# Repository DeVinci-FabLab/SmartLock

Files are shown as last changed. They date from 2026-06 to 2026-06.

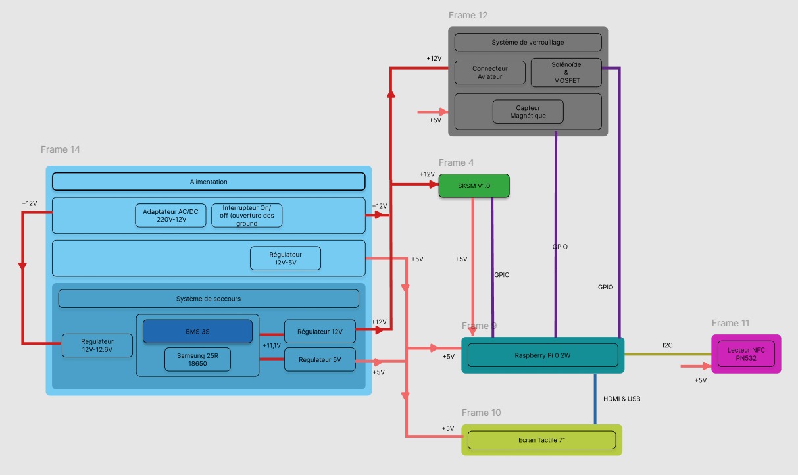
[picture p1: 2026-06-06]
deliverables/2_detailed_design/smartlock_elec_jalon2/smartlock_archi_elec_simplifiée.jpg

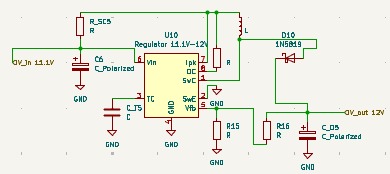
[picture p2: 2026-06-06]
deliverables/2_detailed_design/smartlock_elec_jalon2/smartlock_images_kicad/kicad7.jpg

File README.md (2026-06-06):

# SmartLock

Hub repository for the **DeVinci Fablab SmartLock** system, a badge-controlled connected-locker (*armoire connectée*) platform for managing self-service hardware and inventory.

> [!NOTE]
> This repository holds **no application code**. It is an **index**: each component lives in its own repository and is vendored here as a git **submodule** under [`submodules/`](./submodules), tracked on its `main` branch. Start here for how the pieces fit together, then open the submodule you need.

## Contents

- [Overview](#overview)
- [System architecture](#system-architecture)
- [Components](#components)
- [Design documentation](#design-documentation)
- [Repository layout](#repository-layout)
- [Getting started](#getting-started)
- [Build & deployment](#build--deployment)
- [License](#license)

## Overview

SmartLock controls access to fablab lockers with student NFC badges. Each locker holds an inventory of items (filament, electronic components, supplies). The system handles identification, per-locker permissions, inventory and stock, an append-only audit log, and an admin interface to manage all of it.

It splits into five repositories: the locker **hardware**, a central **backend** that acts as the single source of truth, and an **admin dashboard**.

## System architecture

```mermaid
graph TD
    User(["User · student badge"])

    subgraph locker["Connected locker — hardware"]
        IHM["SmartLock-IHM<br/>Touch interface · Python"]
        PCB["SmartLock-PCB<br/>Custom electronics board"]
        IHM --- PCB
    end

    Reader["SmartLock-Reader<br/>Auxiliary NFC reader<br/>ESP8266 + PN532"]
    Dashboard["SmartLock-Dashboard<br/>Admin web · SvelteKit"]

    subgraph backend["Backend — server"]
        Auth["SmartLock-Authentication-Authorization<br/>FastAPI · single source of truth"]
        KC[(Keycloak<br/>SSO / identities)]
        PG[(PostgreSQL<br/>data + audit log)]
    end

    User -->|NFC badge| IHM
    User -.->|read UID| Reader
    IHM -->|REST: identify, cart, unlock| Auth
    Dashboard -->|REST + JWT| Auth
    Auth --> KC
    Auth --> PG
```

At runtime the Authentication-Authorization API sits in the middle. The dashboard and the locker interface reach Keycloak and PostgreSQL only through it, never on their own. This diagram shows the intended wiring; see each repo for how far its integration has progressed.

## Components

| Component | Local path | Role | Stack |
|---|---|---|---|
| [**SmartLock-Authentication-Authorization**](https://github.com/DeVinci-FabLab/SmartLock-Authentication-Authorization) | [`submodules/SmartLock-Authentication-Authorization`](./submodules/SmartLock-Authentication-Authorization) | Core backend and single source of truth for identities, roles, permissions and audit. Validates NFC badge scans and exposes the REST API the dashboard and the locker interface call. | FastAPI · Keycloak · PostgreSQL |
| [**SmartLock-Dashboard**](https://github.com/DeVinci-FabLab/SmartLock-Dashboard) | [`submodules/SmartLock-Dashboard`](./submodules/SmartLock-Dashboard) | Internal admin web app for inventory, roles, stock, CSV purchase orders and audit history. A REST client of the auth API, with Keycloak SSO. | SvelteKit · shadcn-svelte |
| [**SmartLock-IHM**](https://github.com/DeVinci-FabLab/SmartLock-IHM) | [`submodules/SmartLock-IHM`](./submodules/SmartLock-IHM) | Touch interface on the locker: badge identification, cart, and unlock, talking to a backend REST API. | Python · CustomTkinter |
| [**SmartLock-Reader**](https://github.com/DeVinci-FabLab/SmartLock-Reader) | [`submodules/SmartLock-Reader`](./submodules/SmartLock-Reader) | Standalone auxiliary NFC reader. Shows scanned badge UIDs on a small web page over its own WiFi access point, with a copy button, useful when you need a card's UID. | ESP8266 + PN532 · Arduino |
| [**SmartLock-PCB**](https://github.com/DeVinci-FabLab/SmartLock-PCB) | [`submodules/SmartLock-PCB`](./submodules/SmartLock-PCB) | Custom electronics board for the locker hardware. | *Placeholder repo for now* |

## Design documentation

The `deliverables/` directory contains the full design record produced during the project, organized by phase.

| Folder | Contents |
|---|---|
| [`deliverables/1_state_of_art/`](./deliverables/1_state_of_art) | Concept convergence, state-of-the-art analysis, archival process |
| [`deliverables/2_detailed_design/`](./deliverables/2_detailed_design) | KiCAD schematics (PCB, power, NFC, Pi Zero 2W, lock driver…), component BOM, SolidWorks mechanical models, risk analysis |
| [`deliverables/4_subsystem_tests/`](./deliverables/4_subsystem_tests) | Subsystem test plan and results |
| [`deliverables/5_system_verification/`](./deliverables/5_system_verification) | System test report, user guide, maintenance guide, project retrospective (REX) |

The `CAD/` directory holds two standalone SolidWorks parts (`Boitier_Ext.SLDPRT`, `Cover_Ecran.SLDPRT`) for the external enclosure and screen cover.

## Repository layout

```plain
SmartLock/
├── CAD/                  Standalone SolidWorks parts (enclosure, screen cover)
├── deliverables/         Design and verification documents, organized by phase
│   ├── 1_state_of_art/
│   ├── 2_detailed_design/
│   ├── 4_subsystem_tests/
│   └── 5_system_verification/
├── docs/
│   └── DEPLOYMENT.md     Meta build & deployment guide (start here to deploy)
├── submodules/           Each component, tracked on its main branch
│   ├── SmartLock-Authentication-Authorization/
│   ├── SmartLock-Dashboard/
│   ├── SmartLock-IHM/
│   ├── SmartLock-Reader/
│   └── SmartLock-PCB/
├── .gitmodules
├── LICENSE
└── README.md
```

## Getting started

Clone the hub **with all submodules**:

```bash
git clone --recurse-submodules git@github.com:DeVinci-FabLab/SmartLock.git
```

If you cloned without `--recurse-submodules`, initialize them:

```bash
git submodule update --init --recursive
```

Pull the latest `main` of every component:

```bash
git submodule update --remote
```

Then follow each component's own `README.md` inside its directory to build and run it.

## Build & deployment

The end-to-end order, what to fabricate and deploy first and how the pieces come online, lives in **[`docs/DEPLOYMENT.md`](./docs/DEPLOYMENT.md)**. That file is the top-level guide; each component keeps its own detailed deployment docs in its repository.

## License

This project is licensed under the **MIT License**, Copyright (c) 2025 DeVinci Fablab. See [`LICENSE`](./LICENSE) for details. Each submodule carries its own license (MIT as well at the time of writing).

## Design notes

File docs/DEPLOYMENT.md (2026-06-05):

# Build & Deployment Guide

This is the top-level guide for the whole SmartLock system. It gives the **order** in which to fabricate the hardware and deploy the services, and how each piece comes online. Each component keeps its own detailed deployment docs in its repository; this guide tells you what to do first and how it fits together, then points you there.

## Contents

- [Prerequisites](#prerequisites)
- [Build & deployment order](#build--deployment-order)
  - [Phase 1 — Locker hardware](#phase-1--locker-hardware)
  - [Phase 2 — Identity & backend](#phase-2--identity--backend)
  - [Phase 3 — Admin dashboard](#phase-3--admin-dashboard)
  - [Phase 4 — Commission the locker](#phase-4--commission-the-locker)
- [Shared deployment conventions](#shared-deployment-conventions)

## Prerequisites

- A Linux server reachable from the fablab network. The stack is self-hosted, with no cloud serverless.
- **Docker** + **Docker Compose v2** on the server.
- **Traefik** running as the reverse proxy, with an external Docker network (referenced below as `traefik-network`).
- DNS records pointing your domains (`auth.…`, `api.smartlock.…`, `dashboard.smartlock.…`) to the server's public IP.
- `VOLUMES_PATH` defined in the server environment (see [conventions](#docker-volumes)).

> [!NOTE]
> The containerized services (API, Dashboard) follow the shared conventions in the [last section](#shared-deployment-conventions). Read it once; it applies to every service.

## Build & deployment order

Build from the physical layer up: the locker first, then the backend it talks to, then the admin tooling on top.

```mermaid
graph LR
    A["1 · Locker hardware<br/>PCB · IHM · enclosure"] --> B["2 · Identity & backend<br/>Keycloak → API + PostgreSQL"]
    B --> C["3 · Admin dashboard<br/>SvelteKit"]
    C --> D["4 · Commission<br/>wire IHM → API, enroll badges"]
```

### Phase 1 — Locker hardware

Fabricate and assemble the physical locker before anything else. The rest of the system has nothing to talk to until a locker exists.

1. **PCB**: fabricate or order the custom electronics board, see [`SmartLock-PCB`](../submodules/SmartLock-PCB).
2. **Enclosure and mechanics**: the locker model, lock actuator and wiring.
3. **IHM**: install the touch interface on the locker and flash it, see [`SmartLock-IHM`](../submodules/SmartLock-IHM). You wire it to the API in Phase 4.
4. **Reader** (optional, auxiliary): flash the standalone NFC reader, see [`SmartLock-Reader`](../submodules/SmartLock-Reader). Use it to read a badge UID when you need one.

At the end of this phase you have a powered locker with a touch screen, not yet connected to any backend.

### Phase 2 — Identity & backend

Deploy the single source of truth next. Order matters inside this phase: **Keycloak first**, then the API and database.

1. **Keycloak**: deploy it, then configure the realm, clients, roles and groups.
2. **API + PostgreSQL**: deploy [`SmartLock-Authentication-Authorization`](../submodules/SmartLock-Authentication-Authorization). Migrations run automatically on container start, and the API needs Keycloak reachable.

That repo holds the detailed steps (SSH commands, env vars, realm setup):

- `docs/deployment.md` for the full server deployment guide
- `docs/keycloak-test-guide.md` for the realm, clients, roles and groups
- `docs/system-design.md` for the architecture, auth flows and data model

Check it: the API answers at `https://api.smartlock.devinci-fablab.fr`, with Swagger UI at `/docs`.

### Phase 3 — Admin dashboard

With the API live, deploy the admin web app, see [`SmartLock-Dashboard`](../submodules/SmartLock-Dashboard).

1. Register a Keycloak client for the dashboard (OIDC + PKCE).
2. Fill `web/.env` (API URL, Keycloak issuer and client, session secret), see the dashboard README.
3. Deploy the hardened production image (`just prod`, `adapter-node`, healthcheck on `/health`).

The dashboard is a REST client of the API; it never talks to Keycloak or PostgreSQL directly.

### Phase 4 — Commission the locker

Tie it all together:

1. Point the **IHM** on the locker at the production API URL.
2. Enroll badges: read UIDs with the Reader (or the IHM) and grant locker permissions in the Dashboard.
3. Run a full pass: badge scan → identification → cart → unlock, then confirm the action lands in the audit log.

---

## Shared deployment conventions

The DeVinci Fablab conventions below apply to every containerized service (API, Dashboard). The per-repo deployment docs refer back to them.

### Docker volumes

Volumes live under a single directory to ease management and backup. The server environment defines the root as `VOLUMES_PATH`.

```yaml
services:
  your-service:
    image: ...
    volumes:
      - ${VOLUMES_PATH}/your_service_name/volume1:/my/volume1
      - ${VOLUMES_PATH}/your_service_name/volume2:/my/volume2
```

> [!NOTE]
> A variable like `VOLUMES_PATH`, not managed by the end user, lets you move the volume root without editing every service's configuration.

### Multi-stage Docker images

Service images use multi-stage builds: a shared `base` stage, then split `dev` and production (`serve`) stages, so one `Dockerfile` builds both and you pick the target. Production stages should:

- `EXPOSE` and bind the app to an explicit `--port` (used by the healthcheck and Traefik).
- copy the source into the image so the container runs standalone, with no bind-mounted volume.
- declare a `HEALTHCHECK` that runs a small `healthcheck.sh`.

A typical healthcheck script tries `wget --spider` (or `curl --fail`) against `http://0.0.0.0:<port>/` and exits non-zero on failure.

### CD pipeline → GHCR

Each service ships a CD workflow under `.github/workflows/`. On every push to `main` it builds the production image and pushes it to the GitHub Container Registry:

```yaml
on:
  push:
    branches: [main]

permissions:
  contents: read
  packages: write
```

Per service you only change the build step's `target` (the production stage) and `tags`, following the format `ghcr.io/devinci-fablab/<service_name>:<tag>`: `<service_name>` lowercase with no spaces, and `<tag>` being `latest` plus the commit SHA.

### Traefik integration

In production, do not publish `ports`; Traefik handles routing. Put the service on the external `traefik-network` and add labels (replace `documentation` with your unique service name, lowercase, no spaces):

```yaml
services:
  your-service:
    image: ghcr.io/devinci-fablab/<service_name>:latest
    restart: unless-stopped
    security_opt:
      - no-new-privileges:true
    deploy:
      mode: replicated
      replicas: 2
    labels:
      - 'traefik.enable=true'
      - 'traefik.http.routers.documentation.rule=Host(`docs.devinci-fablab.fr`)'
      - 'traefik.http.routers.documentation.entrypoints=websecure'
      - 'traefik.http.routers.documentation.tls.certresolver=myresolver'
      - 'traefik.http.services.documentation.loadbalancer.server.port=3000'
      - 'com.centurylinklabs.watchtower.enable=true'
    networks:
      - traefik-network

networks:
  traefik-network:
    external: true
```

- `rule=Host(...)`: the domain that routes to this service; it must point to the server's IP.
- `loadbalancer.server.port`: the port the app listens on inside the container (matches `EXPOSE` and `--port`).
- `deploy.replicas`: run N instances for redundancy and load balancing.

> [!NOTE]
> Publishing container ports can override firewall rules, which is usually not what you want. [Read more](https://www.baeldung.com/linux/docker-container-published-port-ignoring-ufw-rules).

### Watchtower

The `com.centurylinklabs.watchtower.enable=true` label lets **Watchtower** pull and redeploy a service when a new image reaches GHCR, closing the loop with the CD pipeline.

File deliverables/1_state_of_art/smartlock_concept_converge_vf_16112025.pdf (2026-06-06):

# SmartLock

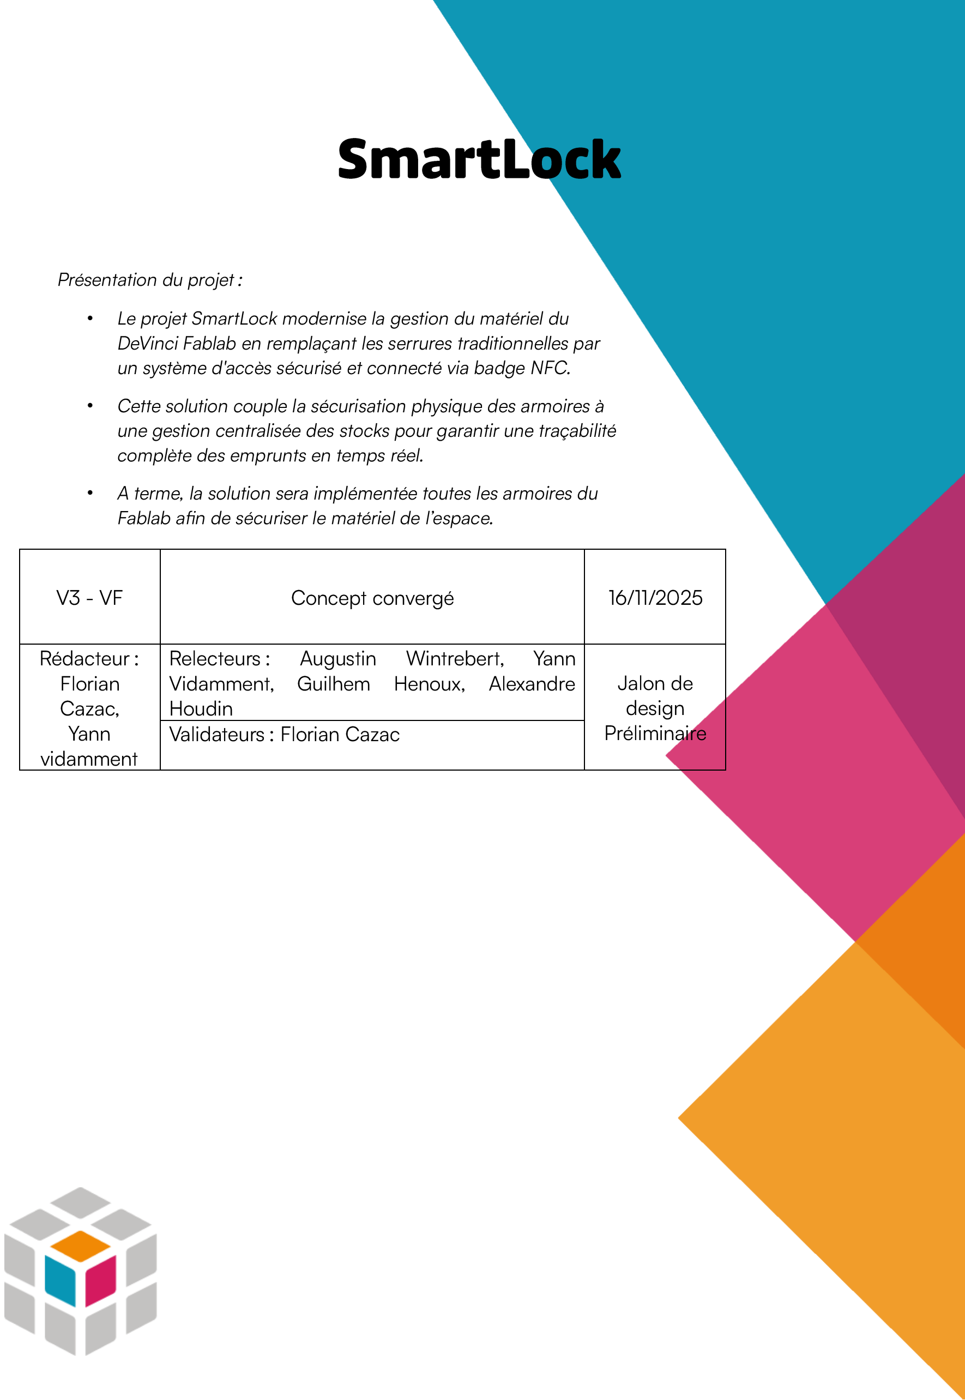
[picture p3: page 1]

V3 - VF | Concept convergé | 16/11/2025

Rédacteur :
Florian
Cazac ,
Yann
vidamment
Relecteur s : | Augustin Wintrebert, | Yann
Vidamment, | Guilhem Henoux, Alexandre
Houdin | | Jalon de design
Validateurs : Florian Cazac | Préliminaire

Présentation du projet :

- Le projet SmartLock modernise la gestion du matériel du DeVinci Fablab en remplaçant les serrures traditionnelles par un système d'accès sécurisé et connecté via badge NFC.
- Cette solution couple la sécurisation physique des armoires à une gestion centralisée des stocks pour garantir une traçabilité complète des emprunts en temps réel.
- A terme, la solution sera implémentée toutes les armoires du Fablab afin de sécuriser le matériel de l’espace.

## Table des matières

## 1. Introduction

Ce document s'inscrit dans le cadre du Jalon de Design Préliminaire. Il formalise le concept convergé de notre système d'armoire connectée, en détaillant l'architecture matérielle et logicielle retenue. S'appuyant sur le retour d'expérience du modèle DVIC, cette solution technique constitue le socle validé nécessaire pour engager la phase de développement détaillé et de réalisation.

## 2. Scénarios d'Utilisation et Protocoles d'Urgence

Cette section présente les séquences d’actions en conditions normales ainsi que les procédures prévues en cas d’incident. L’analyse de ces différents cas d’usage a permis d’identifier clairement les composants nécessaires au bon fonctionnement du système.

2.1. Utilisation Normale (Cas Nominal)
1. Authentification : L'utilisateur s'approche du casier et présente son badge NFC
2. Validation : Le système vérifie les droits d'accès du badge. Si valide, il déclenche
3. Opération : L'utilisateur ouvre la porte, effectue son dépôt ou retrait d'objets,
- Note : Une étape de déclaration d'objets via l'interface tactile est
4. Enregistrement : Le système détecte la fermeture physique de la porte, verrouille le mécanisme et enregistre la transaction (mise à jour de l'inventaire en
5. Confirmation : Un message de succès s'affiche sur l'écran tactile pour informer
6. Fin : L'utilisateur quitte la zone.

2.2. Gestion d'une Coupure de Courant
2.2.1. Courte Durée

Le système permet le maintien des portes par défaut.

1. Détection : Une perte d'alimentation secteur survient pendant une transaction.
2. Continuité : Le système bascule immédiatement sur la batterie interne (autonomie estimée : ~30 min), garantissant notamment l’ouverture des portes.
3. Alerte : Une notification (mail, message, etc.) avertit les membres du bureau de
4. Rétablissement : Lorsque le courant revient, l’alimentation secteur reprend automatiquement sans perturbation du service.
2.2.2. Prolongée
1. Mode Dégradé : La coupure persiste. Le système continue de fonctionner sur
2. Avertissement : L'interface envoie une notification critique concernant
3. Arrêt : Une notification finale s’envoie, puis le système s'éteint proprement via le
4. Continue : Si un utilisateur souhaite accéder à l’armoire alors que le courant n’est toujours pas rétabli, il peut la connecter à une batterie externe pour réalimenter le système et permettre l’ouverture des portes.
5. Reprise : Le système redémarre automatiquement et reprend son fonctionnement normal une fois l'alimentation secteur rétablie.
2.3. Procédure d'Accès d'Urgence (Hardware)
1. Accès physique : En cas de panne critique ou d'urgence absolue, le personnel autorisé intervient sur le boîtier externe (situé au niveau du connecteur aviateur).
2. Effraction contrôlée : Le boîtier est brisé pour accéder à la mécanique interne.
3. Ouverture manuelle : L'opérateur active le module de déverrouillage manuel
4. Maintenance : L'opérateur remet le système en état (réparation du boîtier et vérification électronique) avant la remise en service.

## 3. Mecatronique

3.1. Électronique et Contrôleur

Le cœur du système embarqué a fait l'objet d'une étude comparative approfondie pour équilibrer coût, performance et connectivité.

Unité de Calcul et Affichage Initialement, la | Raspberry | Pi 4 a été envisagée mais
écartée en raison de son coût prohibitif pour un déploiement à grande échelle. De
même, l'ESP32 S3 a été rejeté en raison des complexités liées au développement d'une
interface graphique avancée. Le choix définitif s'est donc arrêté sur la | Raspberry | Pi
Zero 2W . Ce modèle présente l'avantage décisif d'intégrer nativement la | connectivité
WiFi , simplifiant grandement l'architecture réseau tout en restant économiquement viable.

Cette unité pilotera un écran tactile de 7 pouces , servant d'interface directe pour l'utilisateur. Le stockage du système d'exploitation ainsi que les journaux d'événements
(faisant office de "boîte noire") seront assurés par une | carte SD . Enfin, la gestion de
l'arrêt du système sera sécurisée par un module | SKSM V1.0 , garantissant une
extinction propre du système d'exploitation et une gestion optimisée de l'alimentation.
3.2. Capteurs, Mécanismes et Sécurité

La sécurité physique et numérique de l'armoire repose sur des composants sélectionnés pour leur robustesse face aux tentatives d'intrusion.

Authentification RFID/NFC | : Contrairement aux cartes | Mifare Ultralight souvent
utilisées, le projet exige un niveau de sécurité supérieur. Le choix s'est porté sur la technologie NFC MIFARE DESFire EV3 . Cette décision est motivée par le chiffrement avancé des données sur la carte, prévenant efficacement les risques de clonage. En
conséquence, le module de lecture | PN532 a été sélectionné pour sa capacité à lire ce
protocole spécifique, ce que ne permettait pas le module standard | RC522 .

Système de Verrouillage : Le mécanisme de fermeture conserve le principe éprouvé
des armoires du DVIC, utilisant un | solénoïde (Solenoid lock) qui vient bloquer la came
batteuse , voir dessin . La logique de fonctionnement est de type " | Fail Secure " : le
système est verrouillé lorsqu'il n'est pas alimenté (le solénoïde est tendu par défaut) et
ne se déverrouille (rétractation) que lors de l'application d'un courant. Pour compléter
ce dispositif, un capteur magnétique (door sensor) détectera la fermeture effecti ve de la porte, signalant au système de couper l'alimentation du solénoïde pour réengager le verrouillage en toute sécurité. Des LEDs ou un buzzer sont envisag és afin d’inciter l’utilisateur à mettre à jour les stocks.

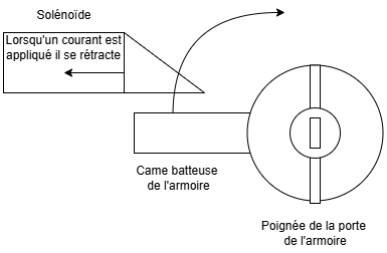
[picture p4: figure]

3.3. Gestion de l'Alimentation

L'alimentation du système est conçue pour être résiliente, avec une source principale
sur secteur transformée (max 12V pour le solénoïde) et un système de secours.

Une batterie de secours est intégrée pour maintenir les fonctionnalités critiques et éviter
le blocage de l'armoire en cas de panne secteur. Le modèle retenu est une | Samsung
25R 18650 (2500 mAh, 3.7V, 20A). Pour adapter la tension de cette batterie aux besoins du système, un convertisseur " boost " (step-up) sera nécessaire afin d'élever la
tension vers une plage de | 9 -12V . L'ensemble du circuit de puissance inclura des
composants de protection indispensables, notamment un | interrupteur | (switch), un
fusible de sécurité, ainsi qu'un connecteur aviateur pour une interface d'alimentation externe robuste .

Figure 1Dessin du système de verrouillage

## 4. Architecture Informatique

L'architecture logicielle du projet est conçue pour assurer une séparation claire entre le serveur central et le client embarqué sur l'armoire, garantissant ainsi modularité et

Infrastructure Serveur | : La partie backend du serveur repose sur | Fast API en
Python , une solution performante pour la gestion des requêtes. Pour l'interface d'administration (frontend), le choix s'est porté sur Svelte , un framework JavaScript. Ce choix marque une rupture avec celui de MyFab (qui utilise Next.js), car Svelte est jugé plus convivial ( user-friendly ) et plus simple à maintenir pour les équipes futures. La persistance des données, notamment la gestion des stocks, est assurée par une base
de données PostgreSQL , tandis que la gestion des utilisateurs et des accès s'orientera vers l'utilisation du protocole LDAP .

Interface Client (Embarqué) : Sur l'armoire elle -même, un client local développé en Python sera exécuté. Son rôle principal est de servir de passerelle, effectuant les appels API nécessaires vers le serveur. L'interface utilisateur (GUI) sera développée à l'aide de la librairie standard TkInter . Toutefois, pour s'affranchir de l'aspect austère par défaut de TkInter et garantir une interface moderne et épurée, le développement s'appuiera
spécifiquement sur la bibliothèque surcouche | CustomTkinter .
Workflow d'autorisation | :
1. L’utilisateur présente son badge NFC (13,56 MHz) au lecteur PN532.
2. Le lecteur récupère l’UID et le transmet au Raspberry Pi via le bus SPI.
3. L’application Python3 envoie la requête d’autorisation au serveur distant via WiFi.
a. Les informations sensibles (UID, identifiant du casier) | ne sont jamais
affichées en clair | sur l’interface.
b. La communication est sécurisée via | SSL/TLS pour chiffrer les échanges.
4. Le serveur, via son API REST, vérifie les permissions de l’utilisateur.
a. Idéalement, il interroge le LDAP pour confirmer que l’utilisateur a le droit d’accéder à cette armoire.
5. Le serveur renvoie un statut d’autorisation : accès accepté ou refusé.
6. Si l’accès est validé, le Raspberry Pi active le relais correspondant pour déverrouiller la serrure.
7. L’interface graphique TkInter affiche simplement le résultat : “Accès autorisé” ou “Accès refusé” , sans divulguer d’informations sensibles.

## 5. Liste de s composants mentionnés

5.1. Gestion de l'Alimentation

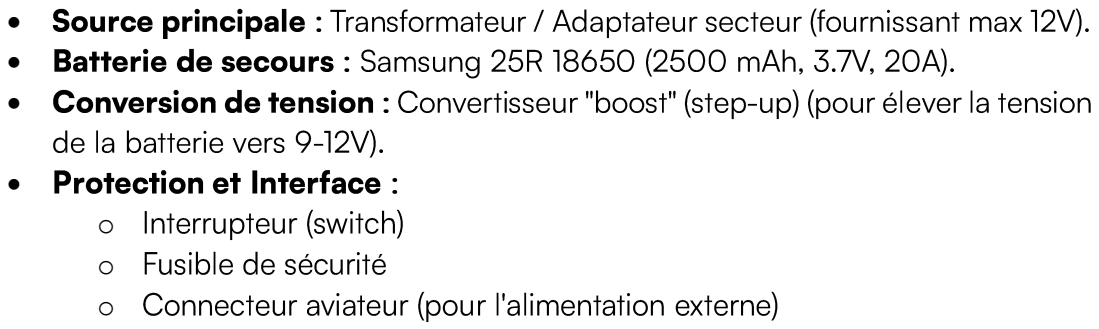
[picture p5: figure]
de la batterie vers 9 -12V). • Protection et Interface : • Interrupteur (switch) • Fusible de sécurité

- Source principale : Transformateur / Adaptateur secteur (fournissant max 12V).
- Batterie de secours : Samsung 25R 18650 (2500 mAh, 3.7V, 20A).
- Conversion de tension : Convertisseur "boost" (step -up) (pour élever la tension
- Connecteur aviateur (pour l'alimentation externe)
5.2. Électronique et Contrôleur
- Unité de calcul : Raspberry Pi Zero 2W (avec WiFi intégré).
- Interface utilisateur : Écran tactile de 7 pouces.
- Gestion alimentation OS : Module SKSM V1.0 (pour l'extinction propre).
5.3. Capteurs, Mécanismes et Sécurité

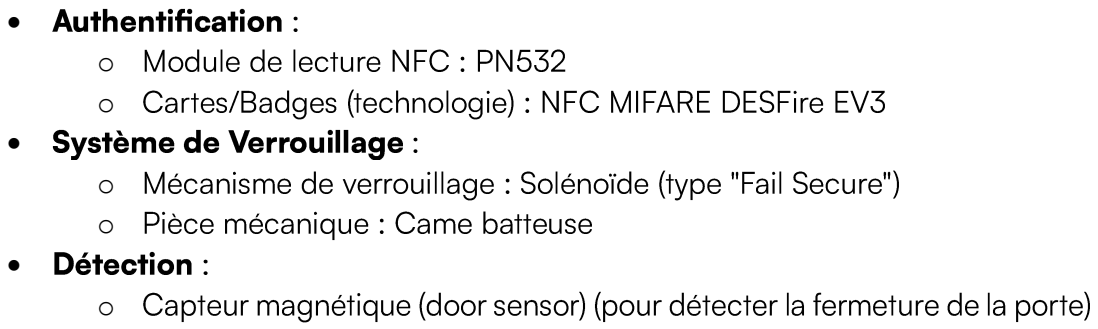
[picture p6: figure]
• Authentification; • Module de lecture NFC : PN532; • Système de Verrouillage :; • Pièce mécanique : Came batteuse • Détection :

- Cartes/Badges (technologie) : NFC MIFARE DESFire EV3
- Mécanisme de verrouillage : Solénoïde (type "Fail Secure")
- Capteur magnétique (door sensor) (pour détecter la fermeture de la porte)
5.4. Signalisation (Composants envisagés)
- LEDs
- Buzzer

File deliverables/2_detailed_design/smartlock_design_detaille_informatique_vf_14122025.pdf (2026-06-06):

# SmartLock

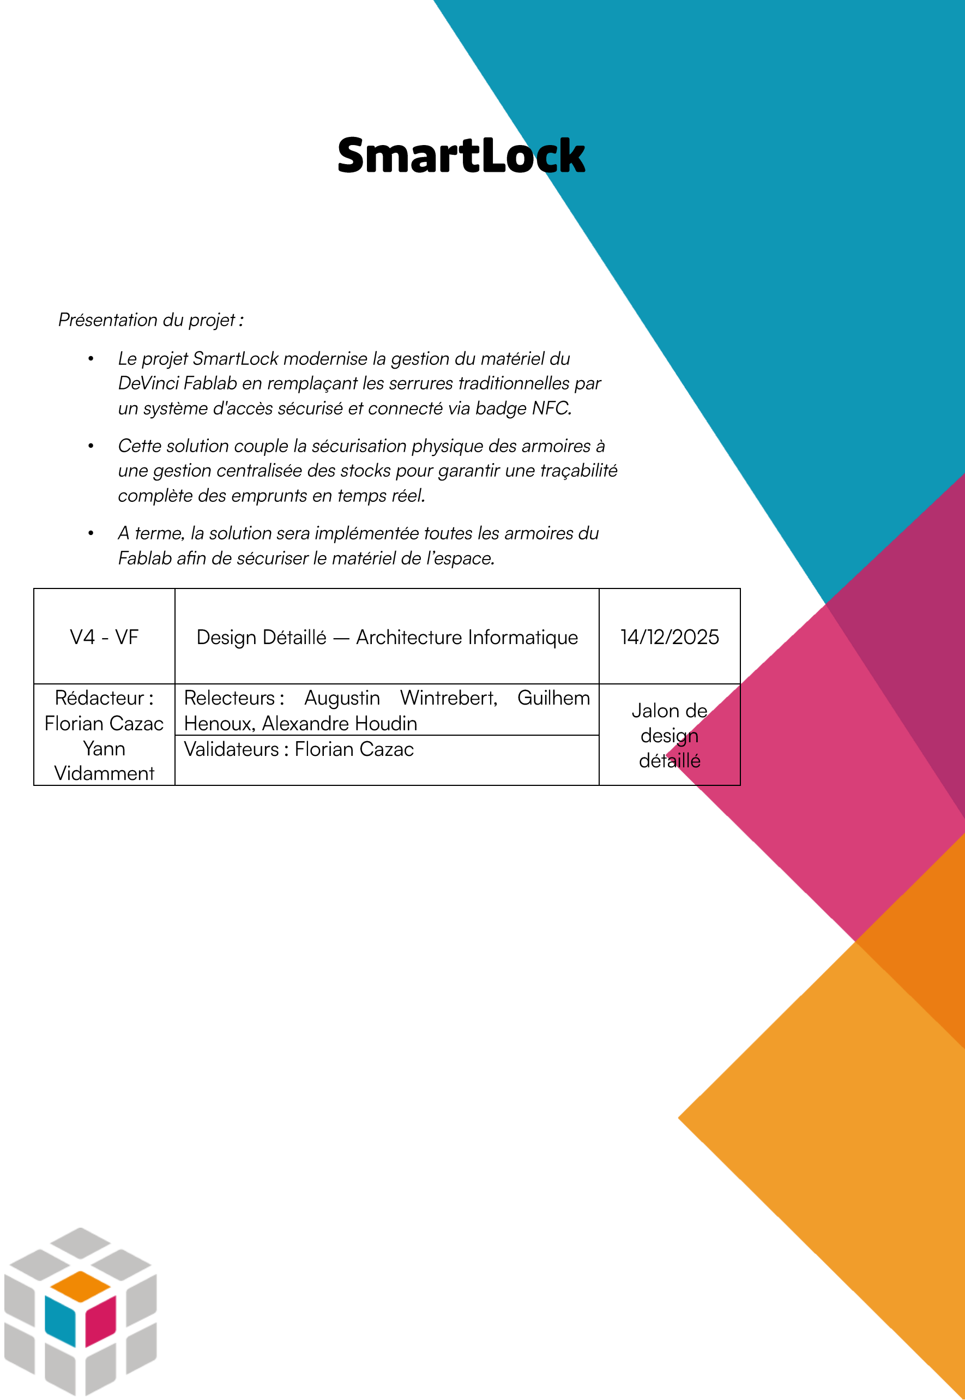
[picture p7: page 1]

V4 - VF | Design Détaillé – Architecture Informatique | 14/12/2025
Rédacteur : Florian Cazac Yann Vidamment | Relecteur s : Aug ustin Wintrebert , Gui lhem Henoux, Alexandre Houdin | Jalon de design

détaillé Validateurs : Florian Cazac

Présentation du projet :

- Le projet SmartLock modernise la gestion du matériel du DeVinci Fablab en remplaçant les serrures traditionnelles par un système d'accès sécurisé et connecté via badge NFC.
- Cette solution couple la sécurisation physique des armoires à une gestion centralisée des stocks pour garantir une traçabilité complète des emprunts en temps réel.
- A terme, la solution sera implémentée toutes les armoires du Fablab afin de sécuriser le matériel de l’espace.

## Table des matières

## 1. Introduction

Ce document définit l'architectur e informatique globale,serveur et logicielle détaillée du client embarqué pour le projet SmartLock.

## 2. Architecture globale

L'architecture logicielle du projet est conçue pour assurer une séparation claire entre le serveur central et le client embarqué sur l'armoire, garantissant ainsi modularité et

2.1. Infrastructure Serveur

Le serveur central est le cerveau du système, hébergé sur une machine distante.

2.1.1. Authentification

Architecture d'authentification

Le système d'authentification du casier intelligent repose sur un compte de service (authentification machine -à-machine) qui interroge l'API Admin de Keycloak

Séquence d'authentification

Lorsqu'une carte NFC est scannée, le processus suivant est exécuté :

1. Lecture : Capture de l'UID de la carte NFC
2. Requête : Envoi de l'UID à l'API backend du casier
3. Authentification : Le système s'authentifie auprès de Keycloak avec les identifiants du compte de service
4. Recherche | : Identification de l'utilisateur possédant l'attribut | nfc_card_id
correspondant
5. Récupération : Obtention des rôles et permissions associés à l'utilisateur
6. Autorisation : Décision d'accès au casier basée sur les rôles de l'utilisateur
7. Traçabilité : Enregistrement de la transaction avec le contexte utilisateur complet

Nous avons fait le choix pragmatique d'utiliser Keycloak dans sa version standard, en exploitant simplement son API Admin et ses comptes de service natifs. Cette approche
nous évite tout développement spécifique complexe : le système est ainsi plus robuste | ,
facile à maintenir, et les mises à jour se font sans risque de régression. | Il centralise la
gestion des identités, qu'il s'agisse de l'accès web (SSO) ou des badges NFC, assurant
une cohérence totale des droits.

2.1.2. Base de Données

PostgreSQL a été retenu comme système de gestion de base de données relationnelle pour assurer la persistance des données métier. Cette solution stocke de manière structurée les inventaires, les configurations des casiers et l'historique complet des

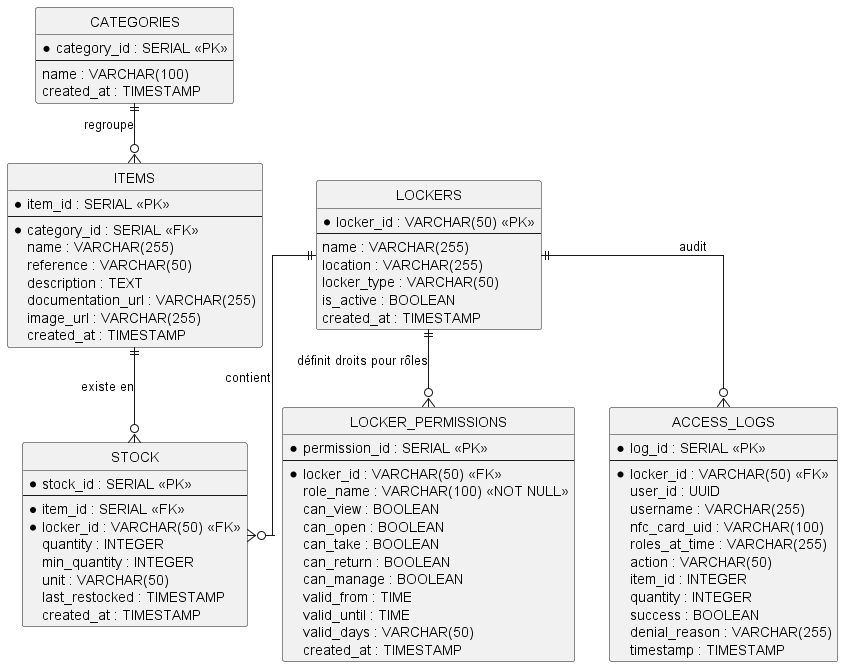
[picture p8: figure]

CATEGORIES : Nomenclature simple permettant d'organiser les produits par familles (ex : "Consommables") pour faciliter la recherche et le filtrage dans l'application.

ITEMS : Le catalogue de référence des produits. Elle décrit "ce que c'est" de manière générique (nom, photo, manuel PDF, référence constructeur), indépendamment de l'endroit où l'objet est stocké ou de la quantité disponible.

LOCKERS : Représente les armoires physiques intelligentes installées. Elle identifie chaque machine de manière unique via son ID technique et précise son emplacement

STOCK : L'état réel de l'inventaire. C'est la table de liaison qui indique "combien" d'unités d'un produit (Item) sont présentes dans une armoire spécifique (Locker), et gère les seuils d'alerte pour le réapprovisionnement.

LOCKER_PERMISSIONS : Le moteur de contrôle d'accès (ACL). Elle définit les règles de sécurité en précisant qui (un utilisateur précis ou un rôle entier comme "équipe de nuit") a le droit d'effectuer quelles actions (voir, ouvrir, prendre) sur quel casier, éventuellement sur des plages horaires définies.

ACCESS_LOGS : Le journal d'audit immuable du système. Elle trace chronologiquement toutes les tentatives d'interaction (réussies ou refusées), en enregistrant l'utilisateur, la carte utilisée, l'action tentée et le casier concerné pour des

2.1.3. Frontend d'Administration

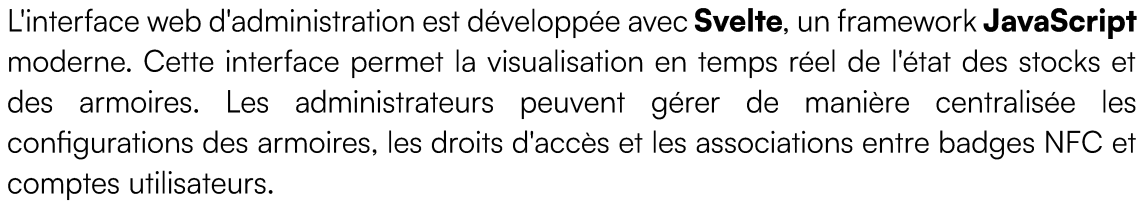
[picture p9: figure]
compt es utilisateurs.

L'interface web d'administration est développée avec Svelte , un framework JavaScript moderne. Cette interface permet la visualisation en temps réel de l'état des stocks et
des armoires. Les administrateurs peuvent gérer de manière centralisée les configurations des armoires, les droits d'accès et les associations entre badges NFC et
2.1.4. Backend API

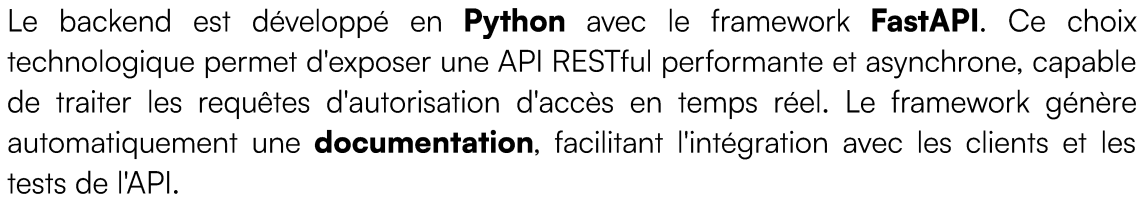
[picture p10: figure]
tests de l'API.

Le backend est développé en | Python | avec le framework | FastAPI . Ce choix
technologique permet d'exposer une API RESTful performante et asynchrone, capable de traiter les requêtes d'autorisation d'accès en temps réel. Le framework génère automatiquement une documentation , facilitant l'intégration avec les clients et les
2.1.5. Déploiement et Conteneurisation
L'ensemble de la stack serveur (Base de données, API, Frontend, Keycloak | ) est
conteneurisé à l'aide de Docker et orchestré via Docker Compose.

2.2. Interface Client
Chaque armoire intelligente est équipée d'un Raspberry Pi Zero | 2 W assurant
l'autonomie fonctionnelle du système en local. Ce nano | -ordinateur constitue l'interface
entre le matériel (lecteurs NFC, Verrou, écran) et le serveur central.
2.2.1. Interface Homme -Machine (IHM)
Une application graphique développée avec | CustomTkinter | offre une expérience
utilisateur moderne et intuitive. Cette surcouche du framework TkInter standard permet de créer des interfaces visuellement attractives, adaptées à un écran tactile de 7
pouces. L'application affiche des retours visuels clairs concern ant le statut d'autorisation (accès accordé ou refusé) ainsi que les indicateurs de connectivité réseau.
2.2.2. Contrôleur Matériel Hardware Abstraction Layer

En arrière -plan de l'interface graphique, un service Python dédié gère les interactions physiques via les ports GPIO du Raspberry Pi. Ce module assure deux fonctions

- Lecture NFC | : Interfaçage avec le lecteur de badge via le protocole | I2C pour
récupérer l'UID des cartes en temps réel.
- Pilotage des verrous : Le Raspberry Pi ne pouvant alimenter directement les serrures, il pilote un module de MOSFET. Ce circuit de puissance agit comme un interrupteur commandé, permettant d'envoyer l'alimentation 12V nécessaire aux solénoïdes pour déverrouiller physiquement l es casiers.

## 3. Architecture Serveur

3.1. Besoins fonctionnels minimaux du serveur
3.1.1. Spécifications matérielles

L'infrastructure requiert les ressources minimales suivantes :

- Stockage : 10 Go + 20 Go de marge d'exploitation pour plusieurs années

État actuel : Le serveur du FabLab couvre intégralement ces besoins. Aucune mise à

3.1.2. Environnement logiciel et sécurité

L'infrastructure s'appuie sur les composants de sécurité suivants :

3.2. Schéma fonctionnel des services sur le serveur

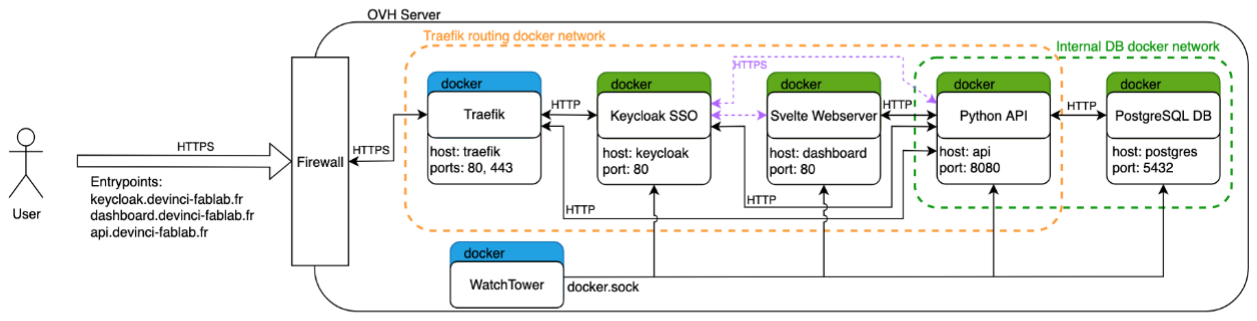
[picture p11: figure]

3.2.1. Architecture des services

L'infrastructure repose sur une architecture microservices conteneurisée comprenant :

Services existants (représentés en bleu) :

- Traefik (reverse proxy et routage)
- Watchtower (mise à jour automatique)

Services ajoutés par Smartlock (représentés en vert) :

3.2.2. Flux de communication

Accès externe : Les utilisateurs accèdent aux services (Serveur Web, API, Keycloak) via Traefik, qui route les requêtes à travers le pare -feu système (Iptables).

Communications internes :

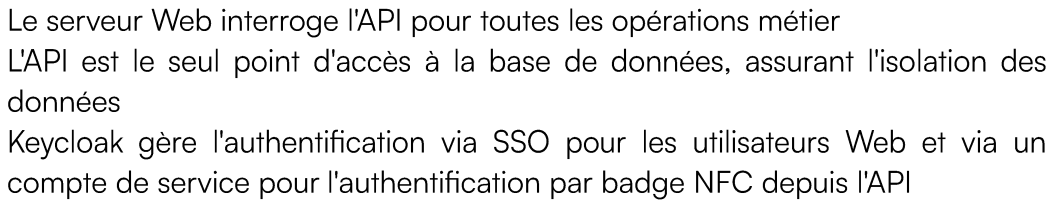
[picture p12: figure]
données

- Le serveur Web interroge l'API pour toutes les opérations métier
- L'API est le seul point d'accès à la base de données, assurant l'isolation des
- Keycloak gère l'authentification via SSO pour les utilisateurs Web et via un compte de service pour l'authentification par badge NFC depuis l'API

Watchtower surveille et met à jour automatiquement les services dès la publication de Nouvelles images Docker (accès en lecture/écriture au socket Docker) pour les

Protocoles de communication :

Réseau interne : | HTTP entre les conteneurs
Réseau externe : | HTTPS uniquement, sécurisé par Traefik avec certificats SSL/TLS

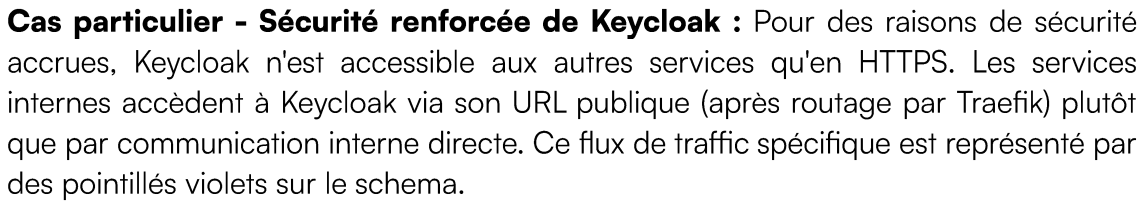
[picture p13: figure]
des pointillés violets sur le schema.

Cas particulier | - Sécurité renforcée de Keycloak : | Pour des raisons de sécurité
accrues, Keycloak n'est | accessible aux autres services qu'en HTTPS. Les services
internes accèdent à Keycloak via son URL | publique (après routage par Traefik) plutôt
que par communication interne directe. Ce flux de | traffic spécifique est représenté par

## 4. Architecture Microprocesseur

4.1. Environnement

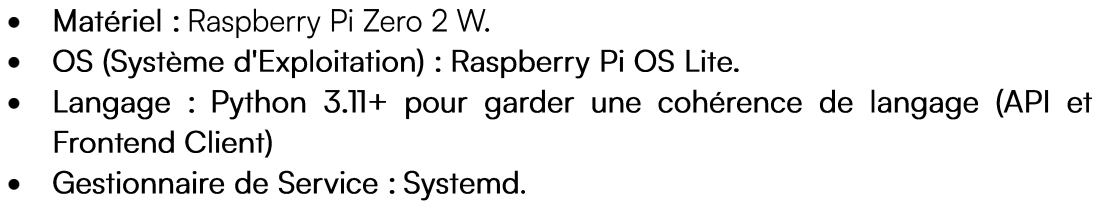
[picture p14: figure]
• Matériel : Raspberry Pi Zero 2 W .; Front end Client); • Gestionnaire de Service :; Systemd .

- OS (Système d'Exploitation) : | Raspberry Pi OS Lite.
- Langage : | Python 3.1 1+ pour garder une cohérence de langage (API et
4.2. Détail des Modules
4.2.1. Module HAL (Hardware Abstraction Layer)

Bibliothèques : gpiozero ( Mosfet/LED), adafruit-pn532 (NFC).

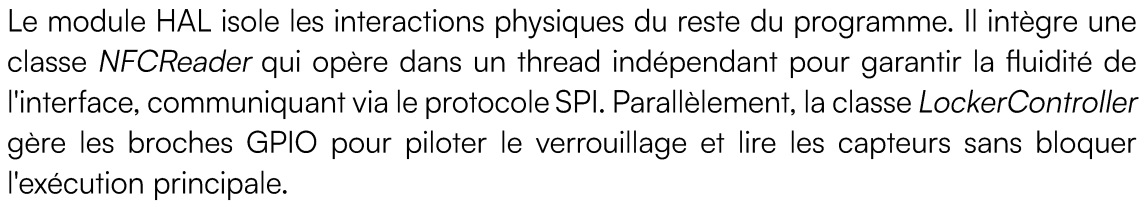
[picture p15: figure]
l'exécution principale.

Le module HAL isole les interactions physiques du reste du programme. Il intègre une classe NFCReader qui opère dans un thread indépendant pour garantir la fluidité de l'interface, communiquant via le protocole SPI . Parallèlement, la classe LockerController gère les broches GPIO pour piloter le verrouillage et lire les capteurs sans bloquer

4.2.2. Module UI

Bibliothèque : CustomTkinter (CTk).

Le module UI, basé sur CustomTkinter , utilise un contrôleur central pour gérer la navigation entre les différents écrans (Accueil, Sélection, Panier, Feedback). Chaque vue est instanciée comme un cadre interchangeable, permettant une transition fluide adaptée au parcours utilisateur défini d ans les wireframes.

4.2.3. Module Session & Logique

La classe SessionManager conserve l'état de l'utilisateur connecté et le contenu de son panier. Elle implémente une sécurité active via un minuteur d'inactivité : l'utilisateur est déconnecté après 90 secondes, et l'écran est mis en veille après 30 secondes supplémentaires pour é conomiser l'énergie.

4.2.4. Module API Client

Bibliothèque : requests

Rôle : Encapsule les appels REST vers le serveur. Gère les Timeouts (si le wifi coupe) et

4.3. Communication
4.3.1. Communication Materielle
- Mosfet : GPIO (Sortie Numérique 3.3V).
- Écran Tactile : HDMI + USB (pour le tactile).
4.3.2. Communication Externe
- Protocole : HTTP/1.1 (REST API) avec payload JSON.
- Sécurité : HTTPS (TLS) fortement recommandé.
- Wifi : Utilisation de la puce Wifi intégrée au Zero 2 W.
4.4. Installation et Configuration

L'ensemble des dépendances est figé dans un fichier pyproject.tom l, permettant une installation automatisée. Le fichier /boot/config.txt est ajusté pour forcer la résolution HDMI (1024x600) et activer l'interface I2C nécessaire au lecteur de badges.

4.5. Gestion des Erreurs et Résilience
En cas de coupure Wi | -Fi, le module API Client intercepte les exceptions réseau.
L'interface affiche alors une pop | -up "Mode Hors Ligne" bloquant temporairement les
nouvelles transactions pour éviter les désynchronisations de stock, tout en tentant une recon nexion automatique en arrière -plan.

## 5. UI/UX de l'interface client

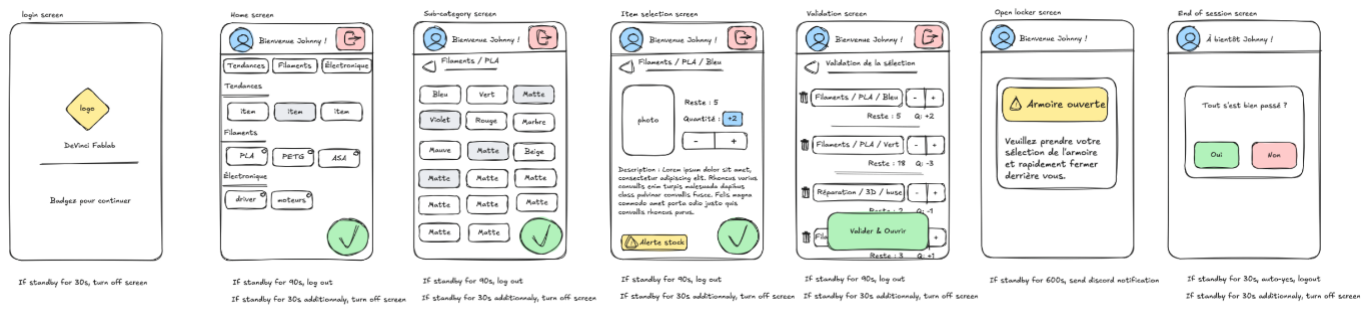
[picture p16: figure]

5.1. Parcours utilisateur et flux d'interaction

L'interface client du casier intelligent a été conçue selon une approche centrée
utilisateur, privilégiant la simplicité et l'efficacité des interactions. Le parcours | utilisateur
se décompose en sept étapes distinctes, | chacune optimisée pour garantir une
5.2. Écran d'accueil

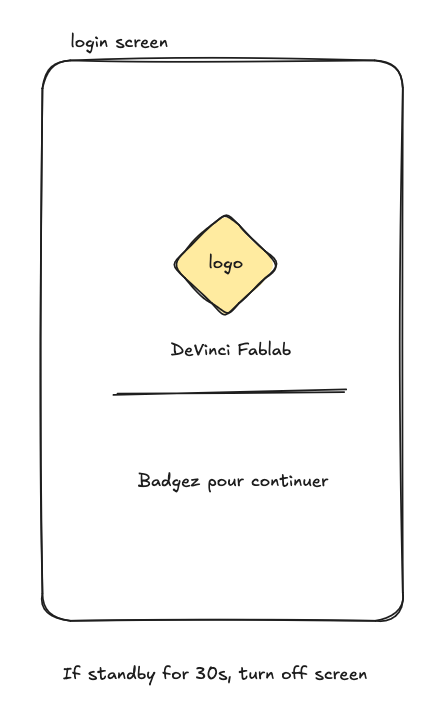
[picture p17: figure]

Description fonctionnelle

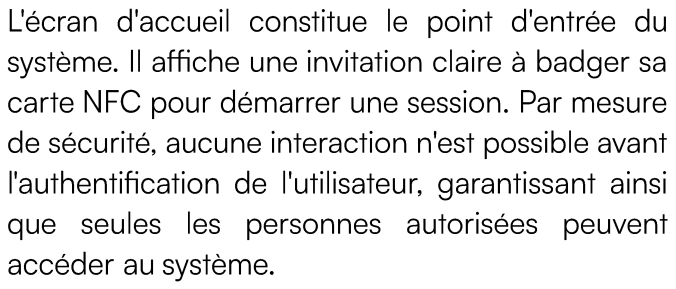
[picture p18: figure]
accéder au système.

L'écran d'accueil constitue le point d'entrée du système. Il affiche une invitation claire à badger sa carte NFC pour démarrer une session. Par mesure de sécurité, aucune interaction n'est possible avant l'authentification de l'utilisateur, garantissant ainsi que seules les personnes autorisées peuvent

5.3. Écran de navigation et sélection

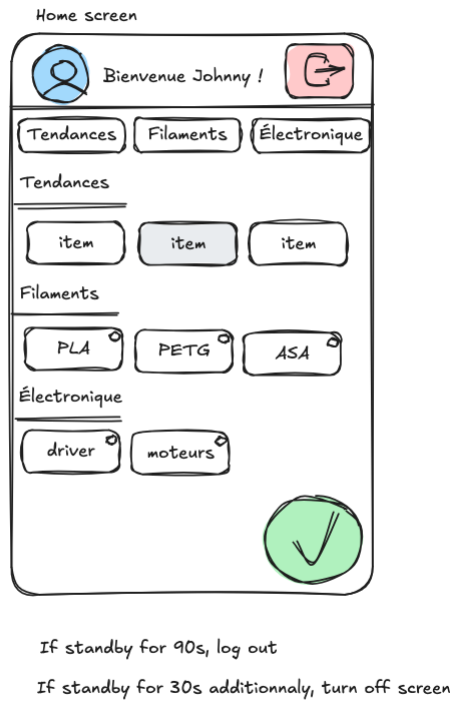
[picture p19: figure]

Vue des catégories de produits

Une fois l'authentification réussie, l'utilisateur accède à l'écran de sélection des catégories de produits, marquant le début de la navigation dans le catalogue. À ce stade, l'utilisateur peut parcourir les différentes catégories disponibles ou choisir de sortir de sa session. L'armoire reste verrouillée durant toute la phase de sélection, ne s'ouvrant qu'après validation finale des produits choisis.

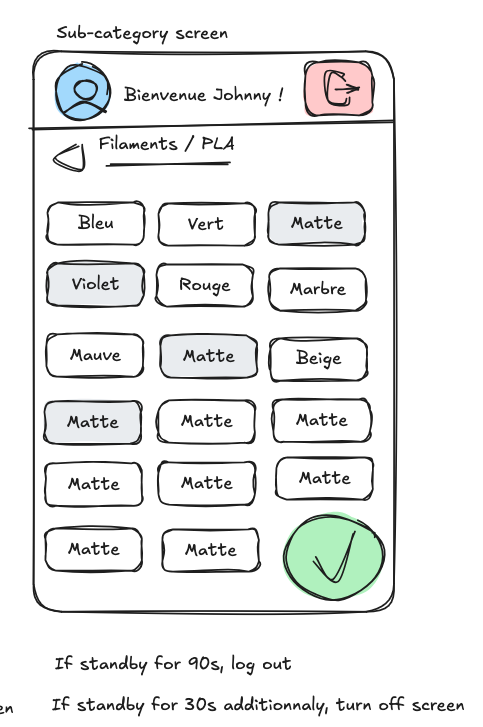
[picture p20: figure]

Vue galerie des articles

L'interface de sélection des articles adopte une présentation en galerie, offrant une vue claire et organisée des produits disponibles dans la catégorie sélectionnée. Cette disposition facilite la consultation rapide du catalogue et permet une identification visuelle immédiate des articles.

5.4. Écran de gestion d'un produit

Fonctionnalités disponibles

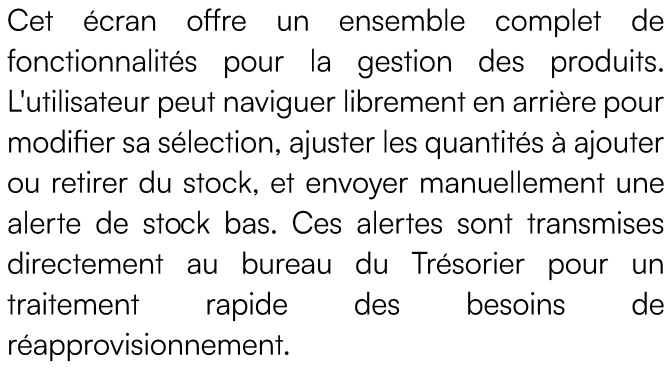
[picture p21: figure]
Cet écran offre un ensemble complet de; traitement rapide des besoins de réapprovisionnement.

fonctionnalités pour la gestion des produits. L'utilisateur peut naviguer librement en arrière pour modifier sa sélection, ajuster les quantités à ajouter ou retirer du stock, et envoyer manuellement une alerte de sto ck bas. Ces alertes sont transmises directement au bureau du Trésorier pour un

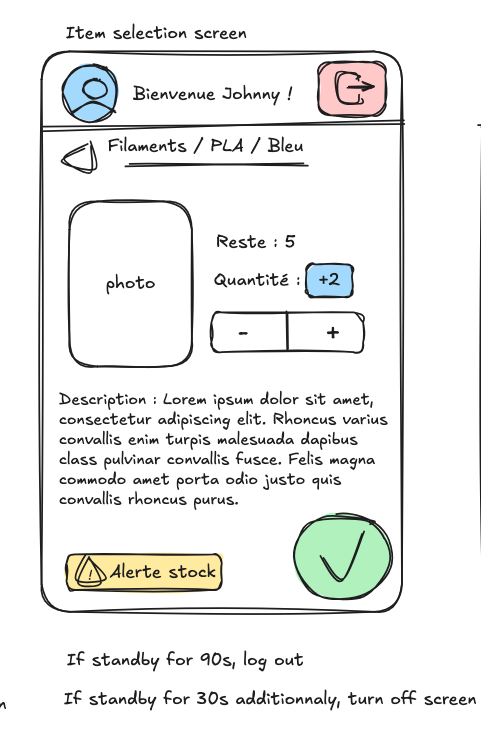
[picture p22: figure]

5.5. Écran de validation finale

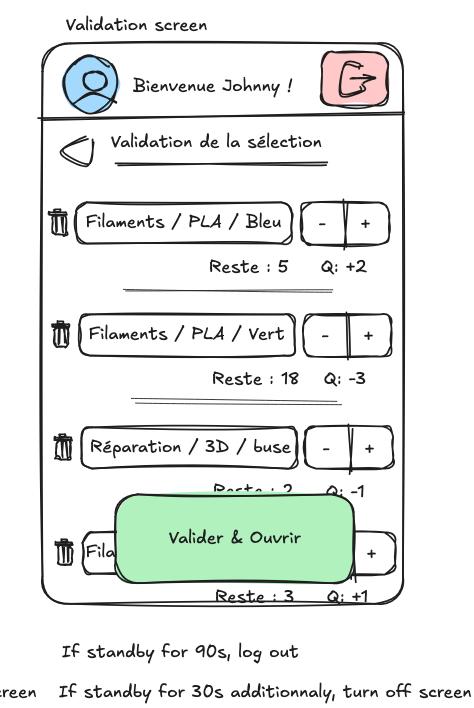
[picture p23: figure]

Point de contrôle avant ouverture

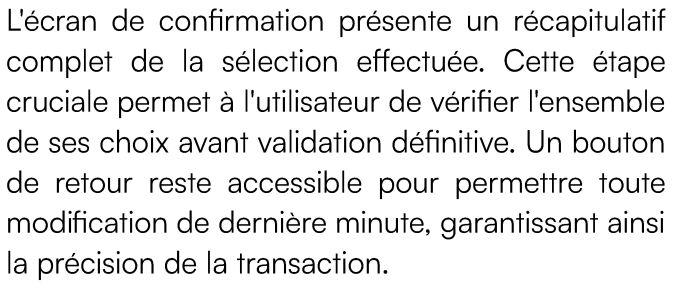
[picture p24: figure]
la précision de la transaction.

L'écran de confirmation présente un récapitulatif complet de la sélection effectuée. Cette étape cruciale permet à l'utilisateur de vérifier l'ensemble de ses choix avant validation définitive. Un bouton de retour reste accessible pour permettre toute modification de dernière minute, garantissant ainsi

5.6. Écran d'accès physique à l'armoire

Phase de manipulation des produits

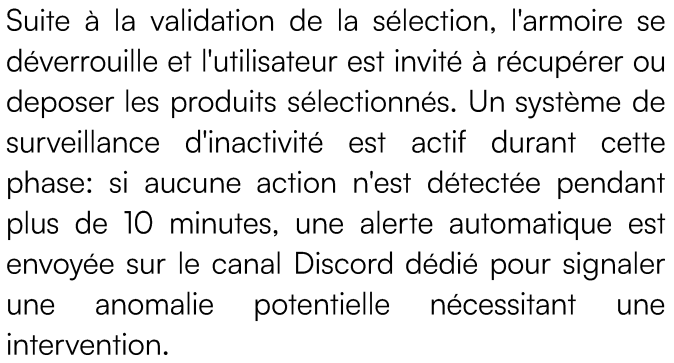
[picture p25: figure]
intervention.

Suite à la validation de la sélection, l'armoire se déverrouille et l'utilisateur est invité à récupérer ou deposer les produits sélectionnés. Un système de surveillance d'inactivité est actif durant cette
phase: si aucune action n'est détectée pendant plus de 10 minutes, une alerte automatique est envoyée sur le canal Discord dédié pour signaler une anomalie potentielle nécessitant une
5.7. Écran de clôture de transaction

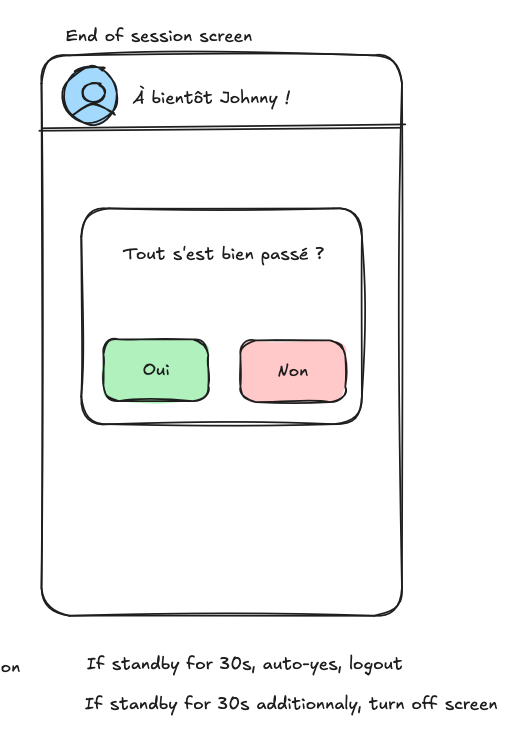
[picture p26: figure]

Validation et gestion d'incidents

L'écran final propose une dernière vérification de la transaction. Si l'utilisateur confirme que tout s'est déroulé correctement, la session se termine automatiquement et l'armoire se verrouille. En cas de problème (produit manquant, erreur de sélection), l'utilisateur dispose d'une option pour rouvrir temporairement l'armoire et effectuer les corrections nécessaires avant de finaliser

## 6. Interface API

6.1. CRUD Item

• GET /items : Retourne tous les items; • POST /items : Cr ée un item {; "name": "Perceuse", "category_id": 3, "reference": "PRC -22", "description": "Perceuse à percussion",

- GET /items/{item_id} : Retourne un item avec son id

"documentation_url": "https://example.com/docs/prc22.pdf","image_url": "https://example.com/images/prc22.jpg"

- PUT /items/{item_id} : Met à jour un item
- DELETE /items/{item_id} : Supprime un item (v érifie qu'il n'est pas en stock)
6.2. CRUD Category
- GET /categories : Retourne toutes les cat égories
- GET /categories/{category_id} : Retourne une cat égorie avec son id
- POST /categories : Cr ée une cat égorie
- PUT /categories/{category_id} : Met à jour une cat égorie
- | DELETE /categories/{category_id} | : Supprime une catégorie (vérifie qu'elle n'a

6.3. CRUD Locker
- GET /lockers : Retourne toutes les armoires
- GET /lockers/{locker_id} : Retourne une armoire avec son id
- PUT /lockers/{locker_id} : Met à jour une armoire
- | DELETE /lockers/{locker_id} | : Supprime une armoire (soft delete : | is_active =
6.4. Stock & Mouvements
6.4.1. Consulter l'inventaire
- GET /lockers/{locker_id}/inventory : Retourne les stocks d'une armoire

"locker_id": "WH -001", "locker_name": "Armoire A - Atelier", "items": [ {; "stock_id": 10, "item_id": 1, "item_name": "Perceuse", "reference": "PRC -22", "category": "Outillage électrique", "quantity": 3, "min_quantity": 5

6.4.3. Ajuster le stock
- POST /stock/in : Ajoute du stock (approvisionnement)

Résultat :

- | Crée log dans | ACCESS_LOGS | : action = "STOCK_IN", | user_id = utilisateur
- POST /stock/out : Retire du stock (pr élèvement)

Résultat :

- | Crée log dans | ACCESS_LOGS | : action = "STOCK_OUT", | user_id = utilisateur

6.5. CRUD Stock
6.5.1. Consulter le stock
- GET /stock : Liste tout le stock (avec filtres optionnels)
- | GET /stock?locker_id=WH -001 | // Stock d'une armoire
- | GET /stock?item_id=1 | // Partout où cet item existe
- | GET /stock?min_quantity_alert=true | // Items en alerte (qty ≤ min_qty)
- GET /stock/{stock_id} : D étails d'une ligne de stock
| {
| "stock_id": 10,
| "item_id": 1,
| "item_name": "Perceuse",
| "locker_id": "WH -001",
| "quantity": 3,
| "min_quantity": 5,
| "unit": "pcs",
| "last_restocked": "2025 -01-10T14:30:00Z"
| }
- GET /items/{item_id}/stock : Stock d'un item dans toutes les armoires
| {
| "item_id": 1,
| "item_name": "Perceuse",
| "reference": "PRC -22",
| "stocks": [
| {
| "stock_id": 10,
| "locker_id": "WH -001",
| "locker_name": "Armoire A",
| "quantity": 3
| },
| {
| "stock_id": 15,
| "locker_id": "WH -002",
| "locker_name": "Armoire B",
| "quantity": 7
| }
| ]
| }

6.5.2. Ajuster le stock (Admin)
- PUT /stock/{stock_id} : Ajuste directement la quantit é

Résultat :

- | Crée log dans | ACCESS_LOGS | : action = "STOCK_ADJUST", | reason, user_id =
6.6. Authentification + Autorisation (NFC)
6.6.1. Accès à l'armoire via NFC

"nfc_uid": "04:AB:CD:EF", "locker_id": "WH -001", "action": "take", "item_id": 10, "quantity": 3

- POST /api/locker/access : Endpoint principal pour l'acc ès aux armoires

Actions valides :

- "take" : Pr élever des items (n écessite item_id et quantity)
- "return": Retourner des items (n écessite item_id et quantity)
- "view" : Consulter l'armoire (optionnel : item_id)
- "manage" : G érer l'armoire (admin only)

Flux :

1. L'API interroge Keycloak (via Compte de Service) pour trouver l'utilisateur
2. Keycloak retourne l'identité de l'utilisateur (UUID, Username) et la liste de ses
3. L'API interroge la table LOCKER_PERMISSIONS
4. Vérification Stock : Si action = "take", vérifie STOCK.quantity .

Réponse succès :

Réponse échec :

"status": "denied", "message": "Permission denied",; "user": "pierre", "locker_id": "WH -001"

"reason": "User does not have can_take permission",

6.6.2. Armoires accessibles par l'utilisateur | (Admin)
- | GET /api/user/lockers : Liste les armoires accessibles par | un utilisateur

Résultat :

6.7. Gestion des Permissions (Admin)
- GET /admin/permissions : Liste toutes les permissions
- | GET /admin/permissions?locker_id=WH | -001 // Permissions d'une armoire
- GET /admin/permissions? role_name = CODIR // Permissions d'un role
- GET /admin/permissions/{permission_id} : D étails d'une permission
- POST /admin/permissions : Cr ée une permissio n
{
"locker_id": "WH -001",
"role_name": "CODIR ",
"can_view": true,
"can_open ": true,
"can_take": true,
"can_return": true,
"can_manage": false,
"valid_from": "08:00",
"valid_until": "18:00",
"valid_days": "MON,TUE,WED,THU,FRI"
}
- PUT /admin/permissions/{permission_id} : Met à jour une permission
- | DELETE /admin/permissions/{permission_id} | : Supprime une permission

6.8. Audit & Logs
- GET /audit/logs : Liste les logs d'acc ès (avec filtres)
- | GET /audit/logs?locker_id=WH -001 | // Accès à une armoire
- | GET /audit/logs?user_id= uuid-pierre | // Actions d'un utilisateur
- | GET /audit/logs?action=TAKE | // Type d'action
- GET /audit/logs?start_date=2025 -01-01&end_date=2025 -01-31 // Période

Résultat :

"roles_snapshot": [" CODIR ", "admin "],

- GET /audit/logs/{log_id} : D étails d'un log

6.9. Code HTTP
Code | Meaning
200 | OK : Succès
201 | Created : Ressource créée
204 | No Content : Suppression réussie
400 | Bad Request : Données invalides
401 | Unauthorized : Non authentifié
403 | Forbidden : Authentifié mais pas autorisé
404 | Not Found : Ressource introuvable
409 | Conflict : Conflit (ex: stock insuffisant)
500 | Internal Server Error : Erreur serveur

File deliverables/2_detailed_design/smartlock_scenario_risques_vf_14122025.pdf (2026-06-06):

# SmartLock


V1- VF | Design Détaillé – Architecture Informatique | 14/12/2025
Rédacteur : Augustin Wintrebert | Relecteur s : Yann Vidamment , Florian Cazac | Jalon de design

détaillé Validateurs : Florian Cazac

Présentation du projet :

- Le projet SmartLock modernise la gestion du matériel du DeVinci Fablab en remplaçant les serrures traditionnelles par un système d'accès sécurisé et connecté via badge NFC.
- Cette solution couple la sécurisation physique des armoires à une gestion centralisée des stocks pour garantir une traçabilité complète des emprunts en temps réel.
- A terme, la solution sera implémentée toutes les armoires du Fablab afin de sécuriser le matériel de l’espace.

## Table des matières

## 1. Introduction

## 2. Permissions des rôles

### Un rôle possède toutes les permissions d’un rôle strictement inférieur dans la

hiérarchie des rôles.

2.1. Hiérarchie des rôles

### Admin>codir>bureau>électronique=3D>membre

Rôle membre

- Consulter les stocks

Rôle 3D :

- Mettre à jour l’inventaire (seulement sur l’armoire à filament)
- Prendre/déposer des items (seulement des bobines de filament)

Rôle électronique :

- Mettre à jour l’inventaire (seulement sur l’armoire électronique)
- Prendre/déposer des items (seulement dans l’armoire électronique)

Rôle bureau :

• Mettre à jour l’inventaire • Prendre déposer des items • Créer un nouveau type d’item • Supprimer un type d’item • Donner/révoquer le rôle 3D

Rôle codir :

- Donner/révoquer le rôle bureau

Rôle admin :

• Donner/révoquer le rôle codir • Donner le rôle admin • Renoncer à son rôle d’admin • Modifier les permissions des rôles • Ajouter des rôles • Supprimer des rôles • Ajouter des permissions • Supprimer des permissions • Modifier l’historique des actions

- Ajouter une armoire
- Supprimer une armoire

## 3. Scenario

3.1. Utilisateur

L’utilisateur peut effectuer les actions suivantes si son rôle le permet :

Pour les actions faisables depuis la borne de l’armoire, l’utilisateur s’avance vers l’écran
et s’authentifie avec son badge. Le lecteur lit le badge et détermine le rôle de
- Consulter les stocks : L’utilisateur a acc ès à la liste des items dans l ’armoire ainsi que leur quantit é, leur description et leur r éférence exacte.
- | Mettre à jour l’inventaire | : L ’utilisateur peut modifier la quantit | é d’un item
disponible ou ajouter un nouvel item (qui | était en quantit é 0)

l’inventaire.

- Prendre/déposer des items : Les portes se déverrouillent, permettant à l’utilisateur de prendre ou de déposer un ou plusieurs items dans l’armoire. Ensuite l’utilisateur referme les portes qui se verrouillent automatiquement, si l’utilisateur ne referme pa s les portes au bout d’un certain temps, un voyant sonore se déclenche. Cette action n’est possible qu’après avoir mis à jour
3.2. Admin

Pour les actions faisables depuis le dashboard, l’utilisateur s’authentifie sur son ordinateur et de la même manière qu’en scannant son badge, ses permissions sont

- Consulter les stocks : L’utilisateur a accès à la liste des items dans l’armoire ainsi que leur quantité, leur description et leur référence exacte.
- Créer un nouveau type d’items : L’utilisateur inscrit le nom, la référence et une description du type d’item qu’il veut ajouter à la base de données.
- Supprimer un type d’item : L’utilisateur sélectionne un type d’item existant à
| supprimer.
- Donner/révoquer un rôle : L’utilisateur sélectionne un autre utilisateur et lui donne/révoque un rôle parmi la liste plus bas.
- Modifier les permissions des rôles : L’utilisateur sélectionne un rôle et lui attribue
| ou enlève des permissions.
- Ajouter un rôle : L’utilisateur crée un nouveau rôle et indique les permissions qui
| lui sont attribuées.

- Supprimer un rôle : L’utilisateur sélectionne un rôle à supprimer, cela révoque par la même occasion le rôle à tous les utilisateurs qui le possédaient.
- Ajouter une permission : L’utilisateur crée une permission. Par défaut, aucun rôle ne la possède, mais cela peut être modifié en modifiant les permissions des rôles par la suite.
- Supprimer une permission : L’utilisateur sélectionne une permission existante et la supprime, cela va automatiquement révoquer cette permission à tous les rôles qui la possèdent.
- Ajouter une action : L’utilisateur inscrit manuellement une action dans l’historique des actions et l’insère en entrant une date/heure de son choix.
- Supprimer une action : L’utilisateur sélectionne une action existante de l’historique et la supprime.
- Ajouter une armoire : L’utilisateur ajoute une armoire ne lui donnant un nom. Par défaut, une armoire est vide.
- Supprimer une armoire : L’utilisateur supprime une armoire existante, pour cela il doit d’abord la vider complètement.

## 4. Risques

4.1. Perte de communication avec le serveur

### En cas de perte de communication avec le serveur, l’utilisateur ne peut pas mettre à jour l’inventaire de l’armoire, il ne peut donc pas non plus l’ouvrir, car cela n’est

possible qu’après avoir mis à jour l’inventaire.

4.2. Perte d’alimentation
En cas de parte d’alimentation secteur, l’armoire est alimentée par une batterie.

### L’utilisateur peut encore effectuer des actions mais il reçoit des alertes. Une fois

l’alimentation secteur rétablie, la batterie est rechargée via l’alimentation secteur.

4.3. Corruption de la base de données

### En cas de corruption de la base de données, l’ensemble des actions concernées par la désynchronisation sont effacées de l’historique. Cela fait perdre des informations mais

permet de garder une cohérence avec le serveur.

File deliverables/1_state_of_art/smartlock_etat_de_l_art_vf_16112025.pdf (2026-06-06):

# SmartLock


V4 - VF | Etat de l’art | 16/11/2025

Rédacteur :
Equipe
Relecteur s : | Augustin Wintrebert, | Yann
Vidamment, | Guilhem Henoux, Alexandre
Houdin

Jalon de
design
Validateurs : Florian Cazac | Préliminaire

Présentation du projet :

- Le projet SmartLock modernise la gestion du matériel du DeVinci Fablab en remplaçant les serrures traditionnelles par un système d'accès sécurisé et connecté via badge NFC.
- Cette solution couple la sécurisation physique des armoires à une gestion centralisée des stocks pour garantir une traçabilité complète des emprunts en temps réel.
- A terme, la solution sera implémentée toutes les armoires du Fablab afin de sécuriser le matériel de l’espace.

## Table des matières

## 1. Introduction

contrôle d’accès formalisé.

La gestion du matériel et la traçabilité des composants sont des défis récurrents pour
les espaces de travail partagés tels que le DeVinci Fablab. Le système actuel, basé sur
des serrures à clé traditionnelles et un suivi | d’inventaire manuel, se heurte à des limites
concrètes : perte de temps, méconnaissance des stocks | disponibles et absence de

Le projet SmartLock vise à résoudre cette problématique : sécurisation, tracabilité,
gestion. Avant de | développer une solution interne, cet état de l’art analyse les
technologies et les produits existants pour la | modernisation des systèmes de stockage

## 2. Typologies et Architectures des Armoires Connectées

objets qu’elle contient.

Une armoire connectée sécurisée est un système de stockage intelligent doté d’un verrouillage électronique et d’une connexion réseau. Elle permet d’identifier les utilisateurs, de contrôler les accès, de tracer les événements et de gérer les stocks via une interface intégrée, afin d’ass urer une sécurité et une traçabilité renforcées des

2.1. Classification par cas d'usage

Le marché des armoires connectées se segmente principalement en fonction du service rendu et de la nature des objets stockés. On distingue quatre grandes familles :

2.1.1. Logistique et E - commerce (Click & Collect)

en extérieur.

Ces armoires, souvent appelées "casiers intelligents" ou "lockers", sont optimisées pour
la logistique du dernier kilomètre. Leur fonction principale est de servir de point de
relais pour la livraison et le retrait de colis. L'accent est mis sur la simplic ité d'utilisation pour le grand public (souvent via QR code ou code PIN) et la robustesse pour un usage
2.1.2. Gestion d'Actifs

Dans ce scénario B2B, l'armoire sert à gérer, tracer et sécuriser des ressources partagées. L'enjeu n'est pas seulement de savoir qui ouvre l'armoire, mais ce qu'il prend

- Outillage industriel ( ex : outils coûteux, EPI).
- Matériel informatique ( ex : ordinateurs portables, scanners).
- Gestion de clés ( ex : agences immobilières, flottes de véhicules). Ces armoires intègrent souvent des technologies d'inventaire (voir Partie 5.1).

2.1.3. Secteur Médical et Pharmaceutique

Il s'agit d'une version à haute sécurité de la gestion d'actifs. Ces armoires gèrent l'accès
à des médicaments, des stupéfiants ou du matériel médical sensible. | La traçabilité doit
être infaillible (logs d'audit stricts) et l'authentification est souvent renforcée ( | ex : badge
+ code, ou biométrie) pour répondre aux normes de conformité (ex | : HDS en France).

Figure 2 Gestion des stocks de; DMI/DMS; en temps réel; (promedeo, s.d.)
automatique X16 (armabo, s.d.)

Figure 3 Amazon Locker , (Amazon, s.d.) | Figure | 1 GoStock Access

2.2. Classification par Architecture de Connectivité
2.2.1. Architecture en Réseau Local (LAN)

L'armoire est un "périphérique" sur le réseau informatique de l'entreprise. Elle est connectée en permanence au serveur de gestion (qui peut être local ou dans le cloud).

• Technologies; : Wi-Fi, Ethernet .; l'infrastructure IT existante.

- Avantage : Très haute fiabilité, communication en temps réel, s'intègre dans
- Inconvénient | : Point de défaillance unique. Si le réseau (WiFi) ou le serveur est
en panne, toutes les armoires sont inopérantes. | (DVIC, s.d.)
2.2.2. Architecture Autonome (Offline / Standalone)
C'est le niveau le plus simple, où l'armoire est un système entièrement embarqué et "air | -
- | Fonctionnement | : La logique de décision est 100% locale. La liste des
utilisateurs autorisés ( ex : les numéros de badges NFC) est stockée physiquement sur un support mémoire interne, typiquement une carte SD .
- Traçabilité : Les journaux d'événements (logs) sont également écrits localement
sur la carte SD, souvent dans un simple | fichier texte (.txt) | ou un fichier CSV.
- | Avantages | : Sécurité maximale contre les attaques réseau (puisqu'il n'y en a
- | Inconvénients | : Gestion opérationnelle très lourde. Pour ajouter/supprimer un
utilisateur ou consulter les logs, une intervention physique est nécessaire ( | ex :
extraire la carte SD, l'éditer sur un PC, puis la remettre dans l'armoire). Il n'y a aucune traçabilité en temps réel. (Santos, s.d.)
2.2.3. Architecture en Réseau Étendu

L'armoire est totalement autonome et communique directement avec Internet via le

- | Technologies | : Cellulaire (4G, 5G), LPWAN (LoRaWAN, Sigfox).
- | Avantages | : Autonomie totale. Peut être installée n'importe où (en intérieur
- | Inconvénients | : Coût d'exploitation (abonnement SIM) et choix technologique
(la 4G est gourmande en énergie ; le LPWAN est économe mais limité à de très

## 3. Composition d'une Armoire Connectée

Une armoire connectée se décompose en deux ensembles fonctionnels principaux : le Groupe de Verrouillage et de Structure (la sécurité physique) et le Groupe de Contrôle et de Connectivité (l'intelligence embarquée)

3.1. Le Groupe de Verrouillage

Ce groupe constitue l'enveloppe physique de l'armoire. Il assure la résistance passive et active aux tentatives d'effraction. Sa conception détermine le premier niveau de

La Structure (Bâti) : Concerne l'armoire elle -même. Les matériaux (acier de différentes épaisseurs, aluminium) et la conception (charnières invisibles, points de soudure) définissent la résistance au forçage, au perçage ou au vandalisme.

Les Actionneurs de Verrouillage : C'est le mécanisme qui verrouille physiquement la porte. L'état de l'art montre plusieurs technologies :

- Gâches électriques : Simples, peu coûteuses, mais offrent une faible résistance à l'effraction.
- Verrous à solénoïde (ou à pêne motorisé) : Un pêne métallique est activement avancé ou rétracté par un moteur ou un électroaimant, offrant une sécurité mécanique supérieure .
- Ventouses électromagnétiques | : Maintiennent la porte fermée par une force
magnétique. L'enjeu est leur mode de défaillance (elles sont souvent "fail | -safe",
c'est-à-dire qu'elles s'ouvrent en cas de coupure de courant, ce qui peut être problématique) .
Les Capteurs | de Retour d'État : L'armoire doit "savoir" si elle est physiquement
fermée. On utilise quasi | -systématiquement des | contacts magnétiques (ILR) | pour
détecter la fermeture de la porte, indépendamment de son état de verrouillage.


Figure 6 Gâches électriques | Figure 5 Verrous à solénoïde | Figure 4 Ventouses électromagnétiques

3.2. Le Groupe de Contrôle et de Connectivité

C'est le "cerveau" du projet "SmartLock". Il gère la logique d'accès, l'identification des utilisateurs, la communication avec le serveur central et la gestion des stocks .

3.2.1. L'Unité de Contrôle

Le cœur logique du système. L'état de l'art couvre un large spectre, allant de
microcontrôleurs | (MCU) simples (ex : famille STM32) à des MCU connectés ( | ex :
ESP32) pour les conceptions à bas coût, jusqu'à des | nano - ordinateurs (ex : Raspberry
Pi) lorsque des logiques complexes (comme la vision par ordinateur) sont nécessaires.
3.2.2. L'Interface Homme -Machine (IHM )

C'est le point de dialogue bidirectionnel entre l'armoire et l'utilisateur.

- Entrées (Input ) : Ce sont les modules qui permettent à l'utilisateur de s'identifier ou de donner des ordres. On y trouve les lecteurs de badges (RFID/NFC), les
claviers à code (PIN), ou les lecteurs biométriques (traités en Partie | 3.2.3 ).
- | Sorties (Output / Feedback | ) : Essentielles pour guider l'utilisateur et confirmer
le statut. L'état de l'art va du plus simple au plus | complexe :
- Feedback minimal : LEDs bicolores ( ex : Vert pour 'Accès autorisé', Rouge pour 'Accès refusé') et un buzzer (pour les confirmations sonores ou les
- Feedback avancé : Écrans (LCD, OLED ou écrans tactiles). Ces derniers permettent d'afficher des instructions ("Passez votre badge"), des messages d'erreur ("Article non reconnu") ou de gérer un inventaire déclaratif (permettre à l'utilisateur de sélectionner ce qu'il prend ).
3.2.3. Les Capteurs d'Inventaire (Gestion de Stock)

Pour les armoires de "gestion d'actifs", cette brique est fondamentale pour savoir "Qu'y

- | Détection par | item : Antennes RFID (UHF ou HF) internes qui scannent le
- | Détection par quantité/ | poids : Jauges de contrainte (pesons) intégrées aux
- | Détection par | vision : Caméras internes couplées à des algorithmes de

## 4. Gestion des Accès et Sécurité Logique

menaces numériques.

Si le groupe de verrouillage (Partie 3.1) constitue la sécurité physique, la gestion des accès et la sécurité logique représentent le "cerveau" et le "système immunitaire" de l'armoire connectée. Cette partie ne se contente pas de bloquer la porte, elle gère l'identité (authentification), les pe rmissions (autorisation) et la protection contre les

4.1. Méthodes d'Authentification

L'authentification est le processus par lequel l'utilisateur prouve son identité au système. L'état de l'art classe ces méthodes en trois grandes catégories, souvent combinées pour augmenter la sécurité (Authentification Multi -Facteurs, ou MFA).

4.1.1. Par "savoir" (Ce que l'on sait )

La méthode la plus simple, reposant sur un secret.

- | Code PIN / Mot de | passe : Implémentation peu coûteuse (simple clavier).
- | Inconvénients | : Faible sécurité, le secret peut être partagé, oublié ou observé
4.1.2. Par "avoir" (Ce que l'on possède | )

Repose sur la possession d'un objet physique ou d'un "jeton" (token) numérique.

- | Badges (RFID / NFC | ) : Très répandu en entreprise. L'état de l'art distingue
fortement les technologies bas - coût ( ex : Mifare Classic 1k), dont la sécurité est compromise et qui sont vulnérables au clonage, des technologies sécurisées ( ex : Mifare DESFire) qui utilisent un chiffrement robuste.
- | Smartphone (via Bluetooth Low Energy | - BLE ) : Le téléphone devient le
"badge". L'accès est géré par une application, ce qui permet des clés d'accès dynamiques.
- | Inconvénients | : L'objet peut être volé, perdu ou, dans le cas des badges bas de
gamme, cloné. (abiova, s.d.)
4.1.3. Par "être" (Ce que l'on est )

Repose sur les caractéristiques uniques de l'individu.

reconnaissance faciale.; oublié.; biométrique . (Xiaohui Yang, s.d.)

- | Biométrie | : Principalement les lecteurs d'empreintes digitales ou la
- Avantages : Très haute sécurité, l'identifiant ne peut être ni volé, ni partagé, ni
- | Inconvénients | : Coût élevé, complexité d'implémentation, et enjeux de
conformité ( ex : RGPD en Europe) sur le stockage et le traitement des données

4.2. Gestion des Autorisations

Une fois l'utilisateur authentifié (le "Qui"), le système doit déterminer ses droits (le "Quoi"). L'authentification est inutile sans une gestion fine des autorisations, qui est gérée par le système central ("backend").

4.2.1. Plateformes de Gestion

Une interface web (administrateur) est nécessaire pour gérer le cycle de vie des accès : enrôler de nouveaux utilisateurs, attribuer des badges, et révoquer les droits en temps

- Modèles de Droits :
- | ACL (Access Control Lists | ) : Un modèle simple où chaque utilisateur
est directement lié à une liste d'armoires (ou de casiers) qu'il peut ouvrir. Rigide mais simple à gérer à petite échelle.
- | RBAC (Role | - Based Access Control | ) : Un modèle plus flexible et
scalable. Des "rôles" sont créés ( | ex : "Étudiant", "Responsable Fablab",
"Admin"). Les permissions sont attribuées aux rôles, et les utilisateurs
4.2.2. Gestion des Accès Dynamiques

Les systèmes modernes vont au -delà des permissions statiques. Ils gèrent des accès temporaires ( ex : un utilisateur externe n'a accès que 24h), des plages horaires (accès autorisé uniquement de 9h à 18h) ou des autorisations à distance (un administrateur peut déverrouiller une armoire depuis son interface).

## 5. Traçabilité, Audit et Gestion d'Inventaire

Alors que la partie précédente se concentrait sur le contrôle d'accès (authentification
et autorisation), cette partie analyse les mécanismes de supervision : comment le
système sait -il ce qu'il contient et comment garde -t-il une trace de ce qui s'est pass é ?
5.1. Méthodologies de la gestion de stock

Pour qu'un stock soit géré, l'armoire doit être capable de savoir quels objets sont pris ou déposés. L'état de l'art identifie trois grandes approches, du plus simple au plus

5.1.1. Le Système Déclaratif
C'est l'approche la plus simple et la moins coûteuse. L'utilisateur s'authentifie ( | ex :
badge NFC), et une interface ( | ex : écran tactile) lui demande de déclarer les articles
- Avantages : Faible coût matériel (ne nécessite qu'une IHM), grande flexibilité (on peut ajouter de nouveaux articles dans la base de données sans modifier
- | Inconvénients | : Repose entièrement sur l'honnêteté et la rigueur de l'utilisateur.
La traçabilité n'est pas "complète" car elle est sujette à l'erreur humaine ou à
5.1.2. Le Système Automatisé par Item (Tagging)

Cette approche vise une traçabilité parfaite en identifiant chaque objet de manière
unique. La technologie dominante est la | RFID (Radio - Frequency Identification) .
- | Fonctionnement | : Chaque outil ou article est équipé d'une étiquette (tag) RFID.
L'armoire est équipée d'antennes fixes qui scannent le contenu en permanence ou à chaque fermeture de porte pour faire l'inventaire.
- Avantages : Traçabilité totale et en temps réel. Le système sait exactement quel item (numéro de série) est présent ou absent.
- | Inconvénients | : Coût (tags, lecteurs, antennes), et défis techniques (les ondes
RFID UHF sont sensibles aux interférences avec le métal et les liquides, ce qui peut être un problème pour certains outils de Fablab). (promedeo, s.d.)

5.1.3. Le Système Automatisé par Quantité ou Emplacement

Cette approche ne suit pas l'item unique, mais la quantité à un emplacement donné.

- | Détection par | Poids : Des jauges de contrainte (pesons) | sont intégrées à
chaque étagère ou casier. Le système connaît le poids unitaire d'un objet ( | ex :
une bobine de PLA) et détecte les variations de poids pour en déduire la quantité
- Avantages : Pas besoin de "tagger" les objets.
- | Inconvénients | : Le poids ne distingue pas deux objets différents mais de même
5.2. La Trace d'Audit

Quelle que soit la méthode d'inventaire, le système doit enregistrer chaque événement dans un journal sécurisé. C'est ce journal qui constitue la "preuve" de la traçabilité.

5.2.1. Le Journal d'Audit

C'est l'enregistrement chronologique et immuable de toutes les actions pertinentes. Pour être exploitable, un "log" doit répondre aux questions fondamentales de la traçabilité (souvent appelées les "5 W") :

- Quand ? (Timestamp précis)
- Qui ? (Identifiant de l'utilisateur ou du badge)
- Où ? (Identifiant de l'armoire et du casier)
- Quoi ? (L'action : "Ouverture", "Fermeture", "Accès refusé", "Prise", "Dépôt")
- Quel(s) objet(s ) ? (Identifiant de l'article, si la méthode d'inventaire le

5.2.2. L'Inaltérabilité et la Centralisation des Logs
- Un log n'a de valeur que si l'on peut lui faire confiance. L'état de l'art insiste sur
- | Centralisation | : Les logs ne doivent pas être stockés uniquement sur
l'armoire (où ils pourraient être effacés). Ils doivent être transmis en temps réel à un serveur centralisé (le "backend").

(Dorigny, s.d.)

- | Inaltérabilité | : Les logs stockés sur le serveur doivent être protégés
contre toute modification (ex : base de données "append -only" ou "read -only" pour les utilisateurs non -admins). Des concepts avancés explorent même l'utilisation de la blockchain pour garantir une immuabilité absolue.
5.3. Les Notifications et Alertes

La collecte de données (logs et inventaire) n'est utile que si elle déclenche des actions. L'état de l'art inclut la mise en place d'un système de notifications.

5.3.1. Alertes de Sécurité
- Tentative d'accès non autorisé ( ex : badge inconnu, badge révoqué).
- Porte laissée ouverte trop longtemps (basée sur le capteur de porte).
- Alerte de maintenance ( ex : batterie faible, perte de connexion réseau).
5.3.2. Alertes d'Inventaire

recommander un article.; heure, une alerte est levée.; de données).

- Stock | bas : | Notification automatique au gestionnaire du Fablab pour
- Item non retourné : Si un outil est pris et n'est pas retourné avant une certaine
- Conformité : Détection d'un item périmé (si les dates sont gérées dans la base

## 6. Exemple concret d’armoire

6.1. Kyubi System – AIR! Smart RFID Cabinet

L’armoire AIR! Smart RFID Cabinet de Kyubi System est un modèle de grande taille (2 m × 2 m × 1 m) destiné à la gestion d’EPI ou d’un grand volume d’outils tagués RFID. Elle permet un inventaire en temps réel, le suivi des mouvements et l’enregistrement des utilisateurs. L’un de ses points forts est sa capacité à fonctionner même en absence de réseau ou de courant, grâce à un mode de secours qui synchronise ensuite les données lorsque la connexion revient. L’armoire peut être intégrée directement à un ERP o u système de gestion existant, ce qui facilite le pilotage global des stocks dans une entreprise.

Cependant, son encombrement important la rend difficile à installer dans des espaces réduits. Elle nécessite également une bonne infrastructure réseau et un système de marquage RFID fiable. Son coût et sa taille la destinent surtout à des environnements


Figure 7 AIR! Smart RFID Cabinet

6.2. Deister Electronic – Smart Asset Lockers (Séries M et L)

Les Smart Asset Lockers de Deister Electronic sont conçus pour la gestion d’appareils électroniques ou d’outils de valeur. La série M peut accueillir jusqu’à 12 compartiments, tandis que la série L offre des compartiments moyens, grands ou extra-grands sel on les besoins. Chaque casier peut être équipé d’un lecteur RFID ou d’un dongle RFID pour identifier précisément chaque objet. L’armoire dispose également d’un mode autonome, d’une batterie de secours et d’une ouverture mécanique d’urgence, ce qui les rend fiables en cas de coupure électrique.

Cependant, ces armoires ne sont pas optimisées pour des volumes très importants ou de gros équipements. Elles conviennent surtout à des stocks sensibles (ordinateurs portables, outils mesurés, appareils électroniques). Leur capacité limitée les rend moins adaptées à des environnements industriels lourds mais très pertinentes pour des salles informatiques ou des services de maintenance interne.


Figure 8 Smart Asset Lockers

## 7. Conclusion

Cet état de l’art a permis de comprendre en profondeur les dimensions architecturales , matérielles et logicielles qui composent une armoire connectée moderne. L’analyse des solutions existantes, allant des projets autonomes low - cost aux systèmes industriels aboutis, met en évidence des approches très différentes mais aussi des lacunes que le projet SmartLock devra co mbler.

La comparaison avec le cahier des charges montre que SmartLock doit se positionner comme une solution hybride, à la fois ouverte, sécurisée et économiquement
accessible. L’exigence d’une | gestion centralisée | des accès conduit naturellement
vers une architecture en réseau local | , tandis que la sécurité impose l’utilisation de
badges NFC de type DESFire | , plus robustes que les solutions d’entrée de gamme
souvent employées dans les projets open -source.

L'exigence d'un "historique non effaçable" (sauf par des administrateurs) est la plus structurante. Elle invalide les architectures " standalone " (logs sur carte SD en .txt), car elles ne sont ni sécurisées ni inaltérables. Cela renforce le besoin d'une architecture centralisée (Partie 5.2) où les logs sont transmis en temps réel à un serveur sécurisé.

L'exigence d'un " panneau de contrôle tactile " pour "mettre à jour les stocks" (parmi 25 à 100 items) oriente le choix de la méthode d'inventaire. Le budget de 650€ rend
les solutions d'inventaire automatisé (comme la RFID UHF) inaccessibles. Le projet
devra donc s'orienter vers un système déclaratif (Partie 5.1.1), où l'IHM tactile (Partie 3.2) est l'élément clé de la gestion des stocks.
Concernant la conception mécanique, | l'état de l'art s'est concentré sur les serrures
(solénoïdes, gâches). Le cahier des charges ajoute | une grosse contrainte mécanique
spécifique : un | "mécanisme automatique" d'ouverture/fermeture | . Cette
obligation accroît la complexité mécanique, augmente | les risques de panne | et peut
dégrader l’expérience utilisateur | , allant potentiellement à l’encontre de l’objectif
final qui est d’assurer une adoption large et une intégration simple | des armoires .

Cet état de l’art servira donc de fondation pour orienter les choix techniques et guider
les arbitrages nécessaires à la conception de l’armoire connectée finale.

## 8. Bibliographie

abiova. (s.d.). Tout savoir sur MIFARE et DESFire en 2025 | . Récupéré sur abiova:
www.abiova.fr/definition -mifare-desfire.html

Amazon. (s.d.). Comment utiliser Amazon Locker, la façon simple et gratuite de retirer
un colis près de chez soi | . Récupéré sur Amazon:
https://www.aboutamazon.fr/actualites/activite -logistique/comment -utiliser-
armabo. (s.d.). | GoStock Access automatique X16 | . Récupéré sur armabo:
http://www.armabo.com/distributeur-automatique -gostock -access/539 -

Deister. (s.d.). Manage equipment and valuables electronically . Récupéré sur deister: https://www.deister.com/en/storage/smart-asset-lockers

Dorigny, M. (s.d.). Centralisation des logs : un atout clé pour la sécurité d’un SI | .
Récupéré sur it - connect: https://www.it - connect.fr/centralisation -des-logs-un-
DVIC. (s.d.). | SMART - LOCK . Récupéré sur Github: https://github.com/DeVinci | -
frontegg. (s.d.). RBAC vs ACL: 5 Key Differences and How to Choose | . Récupéré sur
frontegg: https://frontegg.com/guides/rbac -vs-acl
GROLLEAU. (s.d.). | Armoires connectées G'Connect | . Récupéré sur GROLLEAU:
https://www.grolleau.fr/wp- content/uploads/18618.04B_WEB -
Kyubisystem. (s.d.). | AIR! Cabinet | . Récupéré sur kyubisystem:
https://www.kyubisystem.com/en/products/air - cabinet/
promedeo. (s.d.). | Gestion des stocks de DMI/DMS | . Récupéré sur promedeo:
https://www.promedeo.com/smart - cabinet

reca france. (s.d.). iSTORAGE : gestion des stocks automatisée . Récupéré sur reca: https://www.reca.fr/fr/solutions/istorage -armoires-automatisees/

RS. (s.d.). | Une gestion sécurisée de vos équipements | . Récupéré sur rs | -online:
https://fr.rs-online.com/web/content/services/solutions -inventaire/rs-lockers
Santos, S. (s.d.). ESP32 RFID User Management System with Web Server | . Récupéré sur
randomnerdtutorials: https://randomnerdtutorials.com/esp32 | -rfid-user-

Xiaohui Yang, H. T. (s.d.). Design and Implementation of Goods Storage Cabinet Based
on K210 Face Recognition . Récupéré sur atlantis -press: https://www.atlantis -

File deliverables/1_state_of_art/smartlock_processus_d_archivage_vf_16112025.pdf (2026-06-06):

# SmartLock


V2 - VF | Processus d’archivage | 16/11/2025
Rédacteur : Florian Cazac | Relecteur s : Augustin Wintrebert, Yann Vidamment, Alexandre Houdin | Jalon de design

Préliminaire Validateurs : Florian Cazac

Présentation du projet :

- Le projet SmartLock modernise la gestion du matériel du DeVinci Fablab en remplaçant les serrures traditionnelles par un système d'accès sécurisé et connecté via badge NFC.
- Cette solution couple la sécurisation physique des armoires à une gestion centralisée des stocks pour garantir une traçabilité complète des emprunts en temps réel.
- A terme, la solution sera implémentée toutes les armoires du Fablab afin de sécuriser le matériel de l’espace.

## Table des matières

## 1. Introduction

Ce document définit le processus d’archivage pour | le projet SmartLock . L’objectif
n’est pas la maintenance, mais de définir les actions claires de communication | , de
stockage et de s outils de développement qui signalent la fin d’un projet.

## 2. Outils d’organisation

2.1. Git hub – Code et CAO

Centraliser et versionner le code source, la CAO, ainsi que tous les fichiers techniques

2.1.1. Gestion et Politiques

Les manager s de la plateforme sont Yann Vidamment et Florian Cazac . Les critères d'acceptation des commits sont les suivants : ils doivent être explicites, rédigés en
anglais . Concernant la validation et la création de branches, celles | - ci sont utilisées pour
séparer les développements (par exemple, | feature/authentification ou fix/crud_ route).
Toute branche doit faire l'objet d'une Pull Request | (PR) avant d'être fusionnée dans la
branche principale. Cette PR doit être validée par | les managers de la plateforme, elle
doit avoir été testée et approuvée .
2.1.2. Utilisation et Contenu
Le dépôt contient un | README.md | détaillant le but du projet, les instructions
d'installation et d'utilisation, la structure des répertoires et les contributeurs. La structure
inclut /src pour le code source (API, Interface, etc.), | /cad pour les fichiers CAO (Fusion
360, STL, STEP), et | /docs pour les schémas, diagrammes et captures d'écran.
2.1.3. Environnement et Compilation

package.json; ou pyproject.toml .

Pour recompiler ou réexécuter le code, les éléments requis seront détaillés dans le
README.md . Cela inclut les outils et environnements nécessaires, tels que | Python,
Node. Les configurations, comme les fichiers | Docker ou .env.example , se trouvent
dans le dossier /config . Enfin, les dépendances sont spécifiées dans | requirements.txt ,

2.2. Teams

Teams sert à stocker et organiser les livrables du projet : rapports, présentations, notes de réunion, planning, etc. C'est le lieu de dépôt des documents en général.

2.2.1. Organisation des dossiers
L'organisation des dossiers comprend | /Comptes -rendus pour les CR de réunion
hebdomadaire, /Livrables pour les documents à rendre au FabLab ou à | l’école,
/Présentation pour les slides, affiches et | visuels, et /Ressources pour les références,
2.2.2. Processus de validation

Le dépôt s'agence grâce à un système de fichiers en état de "rédaction" et en état "final".

Les rôles sont définis comme suit :

Le Relecteur relit le travail et le modifie avec l'auteur pour compléter les informations afin que le fichier s'approche de son état final.

Le Validateur donne l'avis final sur la conformité du fichier et peut renvoyer le travail

Le passage à l'état "Final" se fait quand le fichier est nommé correctement, qu'il a été relu et approuvé par le relecteur, et qu'il a été approuvé par le validateur.

2.2.3. Nommage des fichiers

Le nommage des fichiers doit être clair, suivant le format
[projet]_[document ]_[version]_[date].pdf le tout en minuscule | (par exemple,
smartlo ck_etat_de_l_art_ v1_16112025.pdf). L'archivage se fait essentiellement sur le cloud Teams. Les documents sont archivés en format éditable pour éviter de créer des copies en les téléchargeant et rechargeant.

2.3. Discord

Discord centralise la communication rapide et informelle du projet ainsi que

2.3.1. Organisation du serveur Discord
Le serveur est organisé avec un canal dédié | #smartlock et des sous - canaux, structurés
selon les pôles. Pour l'annonce et la communication globale, on utilise | #annonce -
smartlock pour les annonces officielles | , #synthese -de-la-semaine pour le résumé
hebdomadaire des avancées et #tache -a-faire pour les taches données suivant la règle
(Qui, Quoi, Quand, Où ). Les canaux généraux sont | #général -smartlock pour les
discussions générales et | #sujet -de-travail pour le suivi des tâches. Les équipes
techniques disposent d | e canaux spécifiques : | #équipe -mécanique (modélisation,
conception), | #équipe -électronique | (câblage, PCB) et | #équipe -informatique
(architecture, API). Enfin, une Salle de réunion SmartLock sert de canal vocal pour les réunions.
2.4. VSCode

L'objectif de VSCode est de standardiser l'environnement de développement (IDE) pour l'édition du code source. Il est utilisé pour le développement des parties logicielles (API, Interface, etc.). La configuration requiert des extensions recommandées, telles que Python, Docker , JavaScript , Svelte, etc.

2.5. Fusion 360 / Solidworks

Ces outils servent à la Conception Assistée par Ordinateur (CAO) pour la modélisation
3D des pièces mécaniques. Fusion 360 permet de partager les fichiers de modélisation
en temps réel entre les membres de l'équipe. Les fichiers sont exportés au format STE P et STL pour impression ou usinage. Les fichiers sources finaux sont stockés et
versionnés sur GitHub dans le dossier /cad.

## 3. Rendus


3.1. Charte graphique

Chaque document sera équipé d'une page de garde arborant les couleurs du DVFL (DeVinci FabLab). La charte graphique du DVFL ( polices, palette de couleurs, etc.) doit être appliquée à toutes les présentations, affiches et visuels de communication.

3.2. Cartouche

Sur cette page de garde figure un cartouche qui reprendra les informations importantes de la rédaction du document, décrites ci -dessous :

Dans le cas où toute l'équipe participe à la rédaction d'un document, la case «Rédacteur » sera remplie avec «Equipe »

Version | Processus d’archivage | 16/11/2025
Rédacteur | Relecteurs

Jalon Validateurs

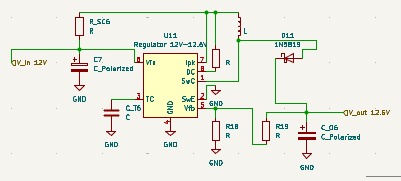
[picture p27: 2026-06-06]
deliverables/2_detailed_design/smartlock_elec_jalon2/smartlock_images_kicad/kicad4.jpg

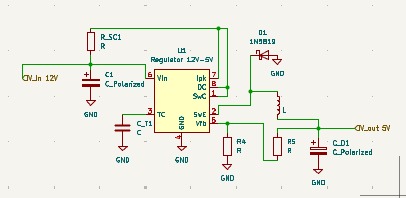
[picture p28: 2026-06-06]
deliverables/2_detailed_design/smartlock_elec_jalon2/smartlock_images_kicad/kicad3.jpg

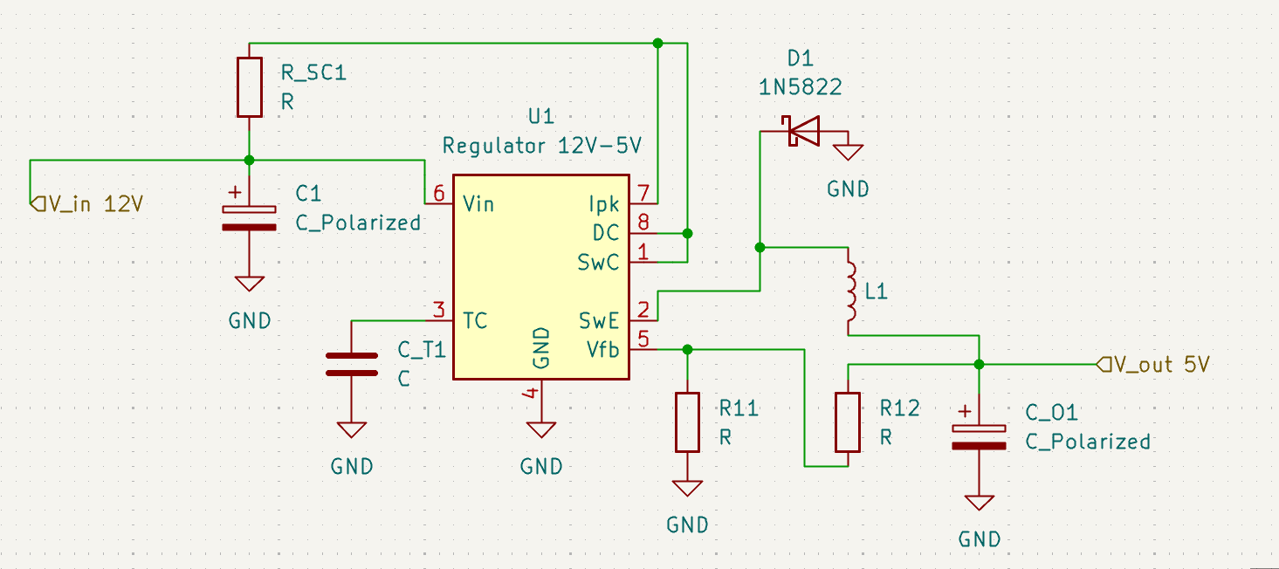
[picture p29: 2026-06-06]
deliverables/2_detailed_design/smartlock_elec_jalon2/smartlock_images_kicad/kicad3.png

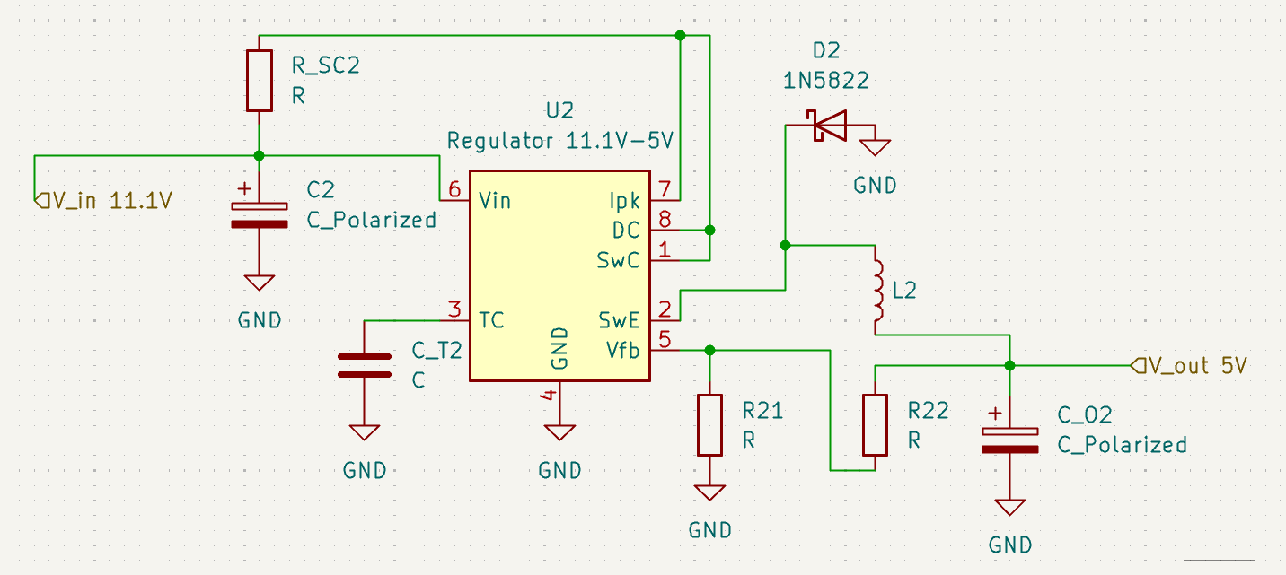
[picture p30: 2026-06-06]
deliverables/2_detailed_design/smartlock_elec_jalon2/smartlock_images_kicad/kicad6.png

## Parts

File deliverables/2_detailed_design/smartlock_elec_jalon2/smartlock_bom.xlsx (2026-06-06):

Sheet: Feuil1
Numéro d'article | Article | Type/Catégorie | Quantité | Fournisseur | Coût Unitaire | Coût Total Estimé | Lien | Note
1 | Rasp 0 12W (Raspberry Pi) | Micro-ordinateur U10 | 3 | Kubii | 18.00 € | 54.00 € | https://www.kubii.com/fr/cartes-nano-ordinateurs/3455-raspberry-pi-zero-2-w.html?src=raspberrypi
2 | BIGTREETECH SKSM V1.0 | Carte sauveuse de donnée J2 | 3 | Biqu | 16.25 € | 48.75 € | https://biqu.equipment/products/bigtreetech-sksm-v1-0
3 | PN532 | Lecteur RFID/NFC U20 | 3 | robotshop | 5.94 € | 17.82 € | https://eu.robotshop.com/products/elecrow-pn532-nfc-module-pn532-rfid-v3-module
4 | 7inch Capacitive Touch Screen LCD (H), 1024×600, HDMI, IPS, Various Systems Support | Écran / IHM | 3 | Gotronic | 47.99 € | 143.97 € | https://www.waveshare.com/7inch-hdmi-lcd-h.htm
5 | Capteur a effet hall | Capteur magnétique U15 | 3 | RS | 8.63 € | 25.89 € | https://fr.rs-online.com/web/p/capteurs-a-effet-hall/2892086 | L'ancienne référence était pour un PCB | https://fr.rs-online.com/web/p/capteurs-a-effet-hall/1811441
6 | Led rouge | Composants elec D20, D21 | 6 | Gotronic | 0.90 € | 5.40 € | https://www.gotronic.fr/art-led-5-mm-l56bhd-2104.htm
7 | Buzzer | Composants elec BZ2 | 3 | Gotronic | 3.60 € | 10.80 € | https://www.gotronic.fr/art-buzzer-sv4-3830.htm
8 | Samsung 25R 18650 | Batterie de secours BT4, BT5, BT6 | 9 | Taklope | 4.30 € | 38.70 € | https://www.taklope.com/samsung/2240-samsung-inr-25r-18650-2500-mah.html
9 | Régulateur CC-CC MC34063ADR | Step-up / Step-down U1-U4 | 25 | RS | 0.57 € | 14.27 € | https://fr.rs-online.com/web/p/convertisseurs-dc-dc/2184547
10 | Interupteur | Protection de circuit SW1 | 3 | RS | 4.50 € | 13.50 € | https://fr.rs-online.com/web/p/interrupteurs-a-bascule/1858229
11 | Solénoïde | Verrou L10 | 3 | JZIK (sinon amazon) | 11.49 € | 34.47 € | https://www.amazon.fr/verrouillage-sol%C3%A9no%C3%AFde-%C3%A9lectrique-s%C3%A9curit%C3%A9-coffres-forts/dp/B074MX923N | Le site ne fonctionne plus go Amazon | https://www.jzk-jzk.com/fr/products/dc-12v-electric-solenoid-lock-assembly-security-lock-for-security-system-safes-door-cabinet
12 | Porte-fusible PF14 | Protection de circuit | 3 | Gotronic | 0.25 € | 0.75 € | https://www.gotronic.fr/art-porte-fusible-pf14-5553.htm
13 | Fusible temporisé 3,15 A | Protection de circuit F1 | 6 | Gotronic | 0.25 € | 1.50 € | https://www.gotronic.fr/art-fusible-temporise-3-15-a-5485.htm
14 | Diode 1N5822 | D1-D4, D10, D11 | 20 | Gotronic | 0.50 € | 10.00 € | https://www.gotronic.fr/art-1n5822-105.htm
15 | Adaptateur AC/DC 220V-12V | Alimentation secteur J8 | 3 | RS | 25.98 € | 77.94 € | https://fr.rs-online.com/web/p/adaptateurs-ac-dc/1753327
16 | Connecteur Aviateur | Connectique J3, J9 | 3 | Audiophonics | 1.90 € | 5.70 € | https://www.audiophonics.fr/en/plane-type-plugs/gx12-connector-2-poles-300v-5a-o5mm-p-9979.html
17 | Mosfet | Connectique Q1 | 3 | RS | 1.28 € | 3.84 € | https://fr.rs-online.com/web/p/transistors-mosfet/5410086 |  | Total 3 armoires | 567.40 €
18 | Cable Hdmi - mini Hdmi | Câblage | 3 | Otronic | 7.00 € | 21.00 € | https://www.otronic.nl/fr/cable-micro-hdmi-vers-hdmi-20-1m-blanc-officiel-ra.html |  | Total 1 armoire | 189.13 €
19 | BMS 3S | Gestion batterie J10 | 3 | Otronic | 2.05 € | 6.15 € | https://www.otronic.nl/fr/circuit-de-protection-bms-3s-avec-fonction-dequili.html
20 | Cable Usb - Micro Usb | Câblage | 3 | Otronic | 2.00 € | 6.00 € | https://www.otronic.nl/fr/cable-usb-a-vers-micro-usb-1-metre-noir.html
21 | Inductance 100µH | L1, L2, L3 | 9 | Gotronic | 0.60 € | 5.40 € | https://www.gotronic.fr/art-self-miniature-100-uh-3521.htm
22 | Inductance 150µH | L4 | 3 | Switch eletronics | 1.78 € | 5.34 € | https://www.switchelectronics.co.uk/products/150%C2%B5h-10-radial-inductor-22r154c
23 | R 13 kΩ | R32 | 5 | e44 | 0.10 € | 0.50 € | https://www.e44.com/composants/composants-passifs/resistances/resistances-precision/0-25-w/resistance-couche-metallique-1-4w-13-kohms-1-MA13K0.html
24 | R 1.5 Ω | R_SC4 | 1 | Gotronic | 0.15 € | 0.15 € | https://www.gotronic.fr/art-10-resistances-1-4w-1-5-8486-2545.htm
25 | R 3.6 kΩ | R12, R22 | 2 | RS | 4.28 € | 8.56 € | https://ma.rsdelivers.com/product/vishay/mrs25000c3601fct00/resistance-film-couche-mince-36k%CF%89-1-06w/6834219P
26 | R 9.1 kΩ | R42 | 1 | Gotronic | 0.25 € | 0.25 € | https://www.gotronic.fr/art-5-resistances-1-2w-9-1-k-8486-8835.htm
27 | R 1.0 kΩ | R41 | 1 | Gotronic | 0.15 € | 0.15 € | https://www.gotronic.fr/art-10-resistances-1-4w-1-0k-8486-2574.htm
28 | R 1.2 kΩ | R11, R21 | 1 | Gotronic | 0.15 € | 0.15 € | https://www.gotronic.fr/art-10-resistances-1-4w-1-2k-8486-2575.htm
29 | R 0.33 Ω | R_SC1, R_SC2 | 2 | Gotronic | 0.55 € | 1.10 € | https://www.gotronic.fr/art-resistance-bobinee-5w-0-33-8486-2813.htm
30 | R 0.47 Ω | R_SC3 | 2 | Gotronic | 0.55 € | 1.10 € | https://www.gotronic.fr/art-resistance-bobinee-5w-0-47-8486-2815.htm
31 | R 1.5 kΩ | R31 | 1 | Gotronic | 0.15 € | 0.15 € | https://www.gotronic.fr/art-10-resistances-1-4w-1-5k-8486-2576.htm
32 | C 560 pF | C_T1 | 1 | Gotronic | 0.10 € | 0.10 € | https://www.gotronic.fr/art-condensateur-ceramique-560-pf-3195.htm
33 | C 100µF/50V | C1, C_O1, C2, C3, C_O3, C4, C_O4 | 15 | Gotronic | 0.20 € | 3.00 € | https://www.gotronic.fr/art-condensateur-radial-100uf-50v-229.htm
34 | C 680 pF | C_T2 | 1 | Gotronic | 0.10 € | 0.10 € | https://www.gotronic.fr/art-condensateur-ceramique-680-pf-3196.htm
35 | C 220 µF / 50V | C_O2 | 5 | Gotronic | 0.10 € | 0.50 € | https://www.gotronic.fr/art-condensateur-radial-220uf-50v-3381.htm
36 | C 150 pF | C_T3 | 1 | Gotronic | 0.10 € | 0.10 € | https://www.gotronic.fr/art-condensateur-ceramique-150-pf-3188.htm
37 | C 120 pF | C_T4 | 1 | Gotronic | 0.10 € | 0.10 € | https://www.gotronic.fr/art-condensateur-ceramique-120-pf-3187.htm
38 | R 330 Ω | R1, R2, R3 | 1 | Gotronic | 0.20 € | 0.20 € | https://www.gotronic.fr/art-10-resistances-1-4w-330-8486-2570.htm

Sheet: Feuil2
Régulateur 12V-5V (page 9) |  |  |  |  | Condensateurs |  |  | Résistances |  |  | Inductances |  |  | Diodes
Composant | Valeur Calculée | Valeur Suggérée (E12/E24) |  |  | 560.00 | pF (céramique) | 2 | 0.33 | Ω | 3 | 100 | µH | 4 | 1N5819 | Schottky
CT (C1) | 564 pF | 560 pF (Céramique) |  | 8 | 100 | µF (chimique 15-25V) | 2 | 1200 | Ω |  | 150 | µH
Rsc (R3) | 0,3 Ω | 0,33 Ω (1/2W) |  |  | 680 | pF | 2 | 3600 | Ω
L (L1) | 87,4μH | 100μH (Courant >1,2 A) |  |  | 220 | µF |  | 1500 | Ω
Co (C2) | 75μF | 100μF (Chimique, 16V ou 25V) |  |  | 150 | pF |  | 13000 | Ω
R1 | 1,2 kΩ | 1,2 kΩ |  |  | 120 | pF |  | 0.47 | Ω
R2 | 3,6 kΩ | 3,6 kΩ |  |  |  |  |  | 1000 | Ω
D1 | Diode Schottky | 1N5819 |  |  |  |  |  | 9100 | Ω
 |  |  |  |  |  |  |  | 1.5 | Ω
Régulateur 11,1V-5V (page 10)
Composant | Valeur Calculée | Valeur Standard (Marché) | Rôle
R1 | 1.2kΩ | 1.2kΩ | Pont diviseur
R2 | 3.6kΩ | 3.6kΩ | Fixe la tension à 5.0V
Rsc | 0.3Ω | 0.33Ω (1W) | Limite le courant pic (~0.9A)
Ct | 620pF | 680pF | Condensateur de timing
L1 | 78μH | 100μH | Inductance (Courant > 1A)
Co | 110μF | 220μF | Condensateur sortie (Low ESR)
D1 | Schottky | 1N5819 | Diode de roue libre
Régulateur 11,1V-12V (page 11)
Composant | Valeur Calculée | Valeur Standard (Marché) | Rôle
R1 | 1.5kΩ | 1.5kΩ | Pont diviseur
R2 | 12.9kΩ | 13kΩ | Fixe la tension à ~12.08V
Ct | 140pF | 150pF | Critique : Valeur très faible due au rapport cyclique court.
L1 | 82μH | 100μH | Inductance (Courant > 0.5A)
Rsc | 0.66Ω | 0.47Ω ou 0.5Ω | Limite de courant (~0.6A pic)
Co | 10μF (min) | 100μF | Électrolytique (25V)
D1 | Schottky | 1N5819 | Diode rapide
Régulateur 12V-12,6V (page 12)
Composant | Valeur Calculée | Valeur Standard Recommandée | Note Technique
R1 | 1kΩ | 1kΩ
R2 | 9.08kΩ | 9.1kΩ | Donne Vout≈12.62V
Ct | 120pF | 100pF ou 120pF | Attention : Valeur très faible car le temps d'activation (ton) est court.
L1 | 145μH | 150μH | Pour Iout=100mA
Rsc | 1.36Ω | 1.2Ω ou 1.5Ω | Limite le courant pic (Ipk) à ~250mA pour protéger la charge.
Co | 10μF (min) | 100μF | Électrolytique (Low ESR)

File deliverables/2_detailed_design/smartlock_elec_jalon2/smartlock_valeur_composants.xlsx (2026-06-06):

Régulateur 12V-5V (page 9)
Composant | Valeur Calculée | Valeur Suggérée (E12/E24)
C_T1 | 564 pF | 560 pF (Céramique)
R_SC1 | 0,3 Ω | 0,33 Ω (1/2W)
L1 | 87,4μH | 100μH (Courant >1,2 A)
C_01 | 75μF | 100μF (Chimique, 16V ou 25V)
R11 | 1,2 kΩ | 1,2 kΩ
R12 | 3,6 kΩ | 3,6 kΩ
D1 | Diode Schottky | 1N5819
Régulateur 11,1V-5V (page 10)
Composant | Valeur Calculée | Valeur Standard (Marché) | Rôle
R21 | 1.2kΩ | 1.2kΩ | Pont diviseur
R22 | 3.6kΩ | 3.6kΩ | Fixe la tension à 5.0V
R_SC2 | 0.3Ω | 0.33Ω (1W) | Limite le courant pic (~0.9A)
C_T2 | 620pF | 680pF | Condensateur de timing
L2 | 78μH | 100μH | Inductance (Courant > 1A)
C_O2 | 110μF | 220μF | Condensateur sortie (Low ESR)
D2 | Schottky | 1N5819 | Diode de roue libre
Régulateur 11,1V-12V (page 11)
Composant | Valeur Calculée | Valeur Standard (Marché) | Rôle
R31 | 1.5kΩ | 1.5kΩ | Pont diviseur
R32 | 12.9kΩ | 13kΩ | Fixe la tension à ~12.08V
C_T3 | 140pF | 150pF | Critique : Valeur très faible due au rapport cyclique court.
L3 | 82μH | 100μH | Inductance (Courant > 0.5A)
R_SC3 | 0.66Ω | 0.47Ω ou 0.5Ω | Limite de courant (~0.6A pic)
C_03 | 10μF (min) | 100μF | Électrolytique (25V)
D3 | Schottky | 1N5819 | Diode rapide
Régulateur 12V-12,6V (page 12)
Composant | Valeur Calculée | Valeur Standard Recommandée | Note Technique
R41 | 1kΩ | 1kΩ
R42 | 9.08kΩ | 9.1kΩ | Donne Vout≈12.62V
C_T4 | 120pF | 100pF ou 120pF | Attention : Valeur très faible car le temps d'activation (ton) est court.
L4 | 145μH | 150μH | Pour Iout=100mA
R_SC4 | 1.36Ω | 1.2Ω ou 1.5Ω | Limite le courant pic (Ipk) à ~250mA pour protéger la charge.
C_04 | 10μF (min) | 100μF | Électrolytique (Low ESR)

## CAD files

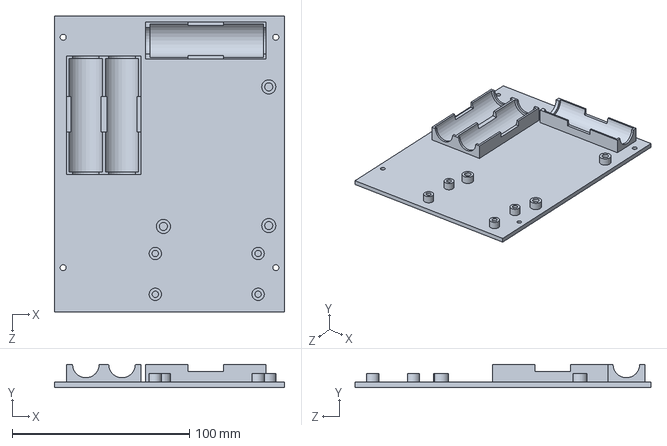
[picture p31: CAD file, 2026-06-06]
CAD/Cover_Ecran.SLDPRT
130.0 x 13.0 x 167.0 mm

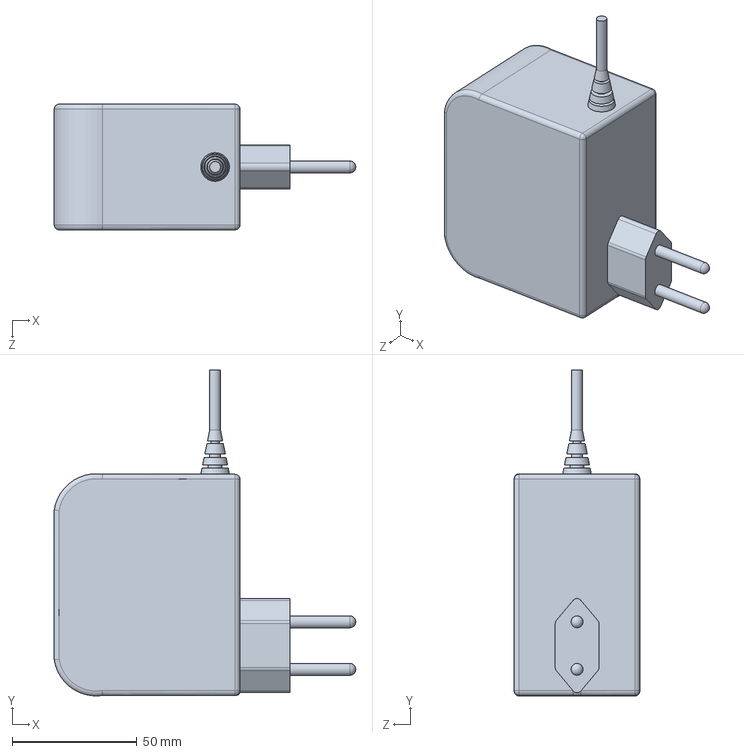
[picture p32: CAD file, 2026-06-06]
deliverables/2_detailed_design/smartlock_mode_jalon2/transformateur.SLDPRT
120.9 x 130.7 x 50.4 mm

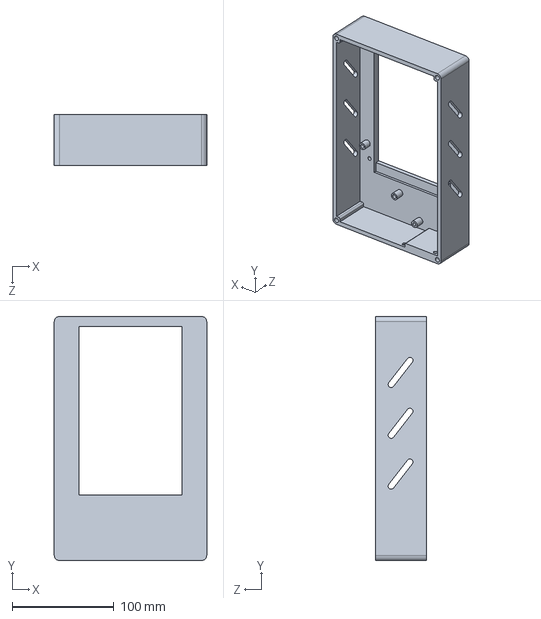
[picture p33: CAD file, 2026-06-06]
CAD/Boitier_Ext.SLDPRT
150.0 x 240.0 x 50.0 mm

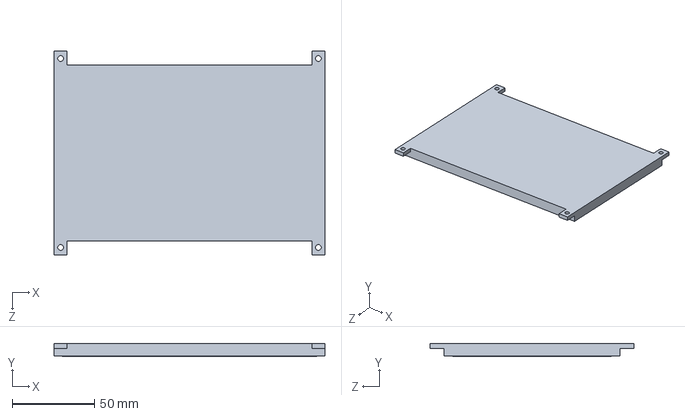
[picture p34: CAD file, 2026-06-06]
deliverables/2_detailed_design/smartlock_mode_jalon2/Waveshare 7 inch screen HDMI 1024×600 v2.SLDPRT
164.9 x 8.00 x 124.3 mm

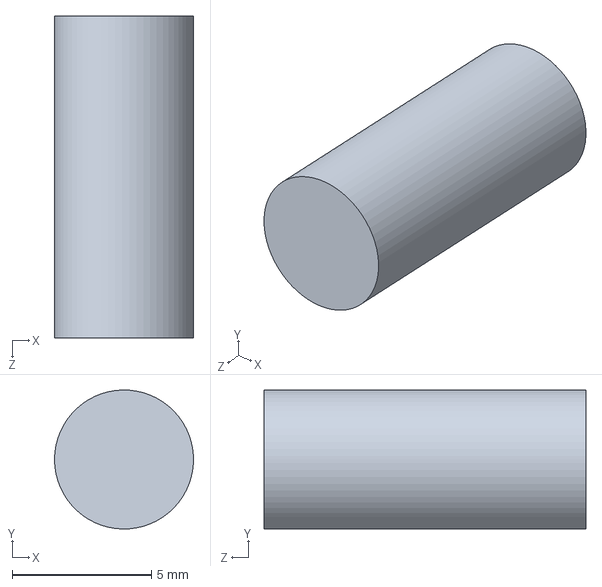
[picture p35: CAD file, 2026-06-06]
deliverables/2_detailed_design/smartlock_mode_jalon2/Cable_Ext.SLDPRT
5.00 x 5.00 x 11.6 mm

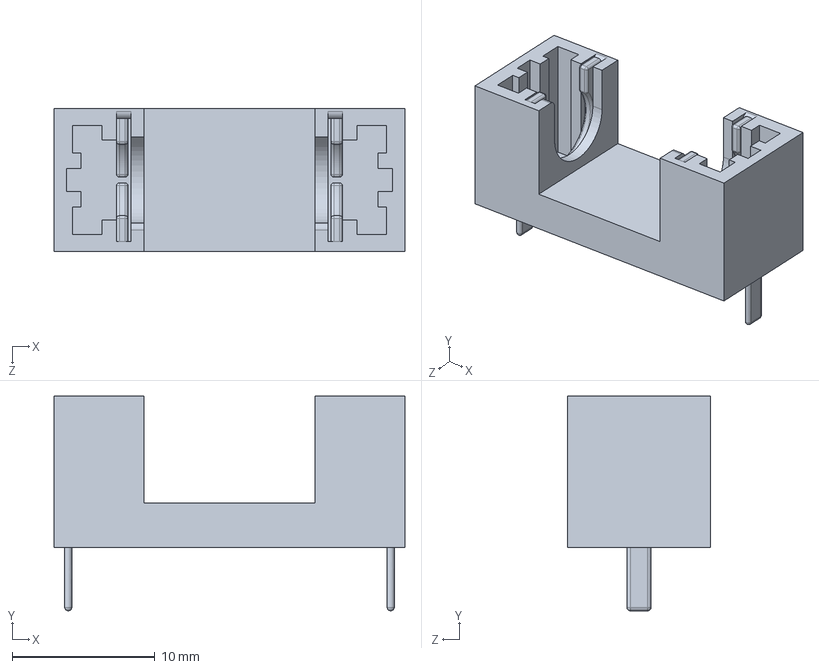
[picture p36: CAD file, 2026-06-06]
deliverables/2_detailed_design/smartlock_mode_jalon2/FH1-200CK-B_HONGJU v2 (Black).SLDPRT
24.6 x 15.0 x 10.0 mm

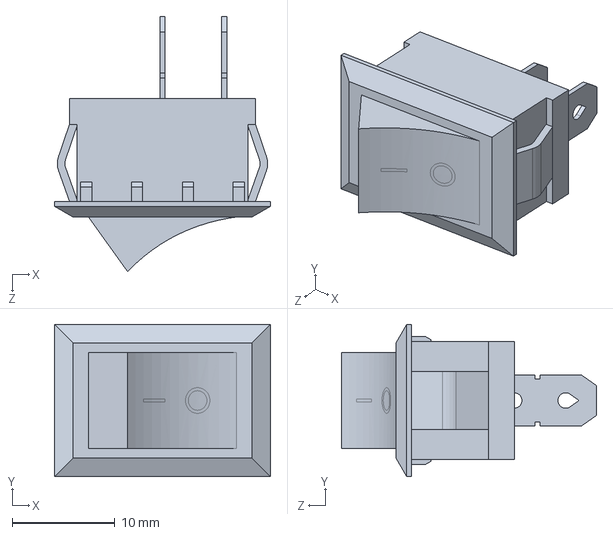
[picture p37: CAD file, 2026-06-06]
deliverables/2_detailed_design/smartlock_mode_jalon2/RockerSwitch.SLDPRT
21.0 x 14.8 x 24.8 mm

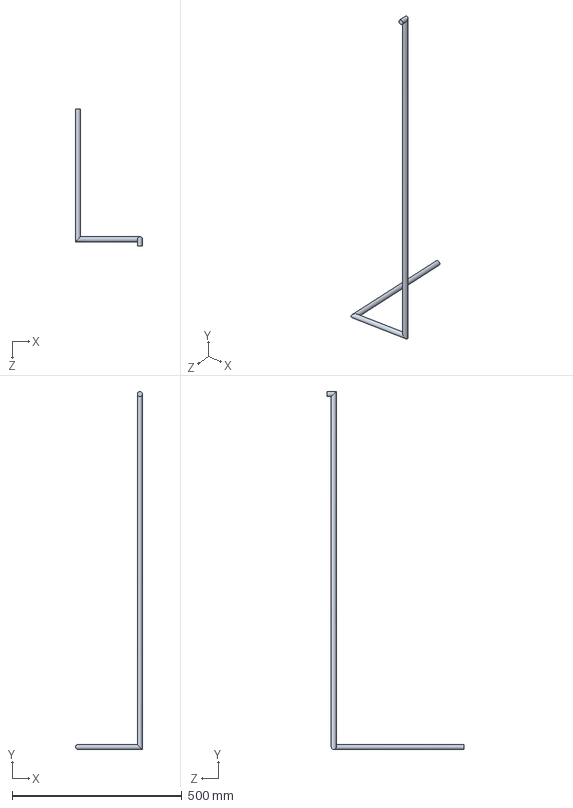
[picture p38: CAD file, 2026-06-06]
deliverables/2_detailed_design/smartlock_mode_jalon2/cable_principal.SLDPRT
197.0 x 1053.0 x 403.0 mm

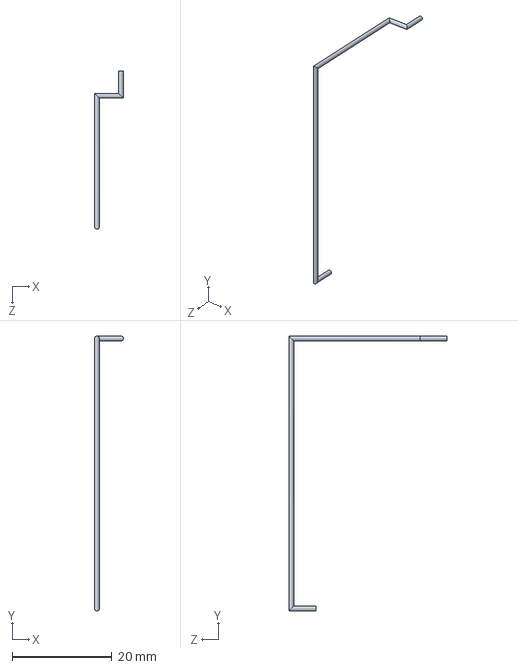
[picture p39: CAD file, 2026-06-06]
deliverables/2_detailed_design/smartlock_mode_jalon2/Cable_SCL.SLDPRT
5.82 x 55.2 x 31.8 mm

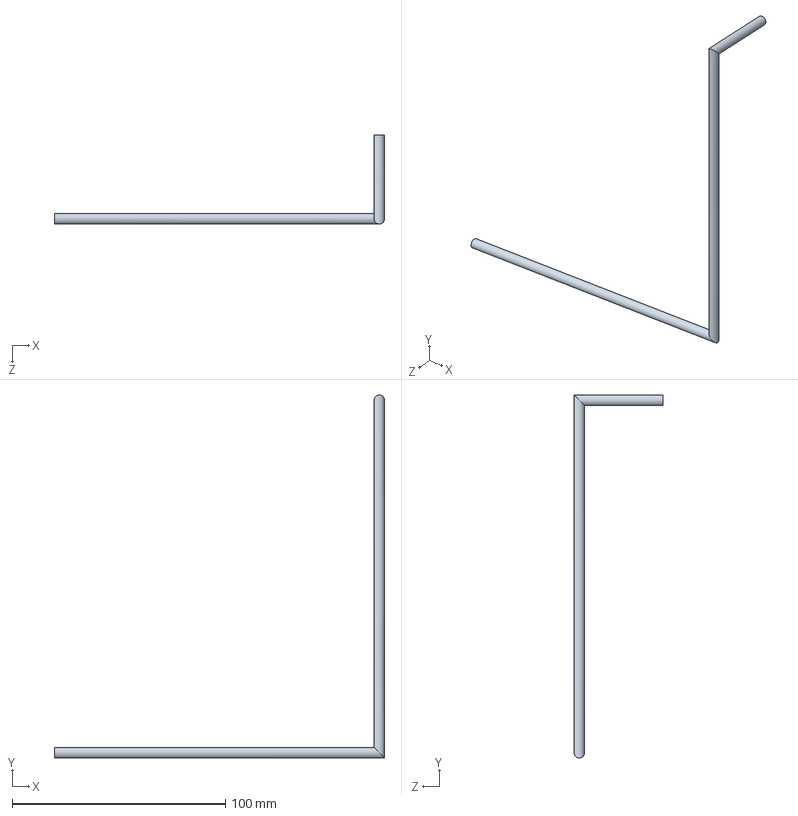
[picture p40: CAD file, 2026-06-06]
deliverables/2_detailed_design/smartlock_mode_jalon2/Cable_Sensor.SLDPRT
155.0 x 170.3 x 41.7 mm

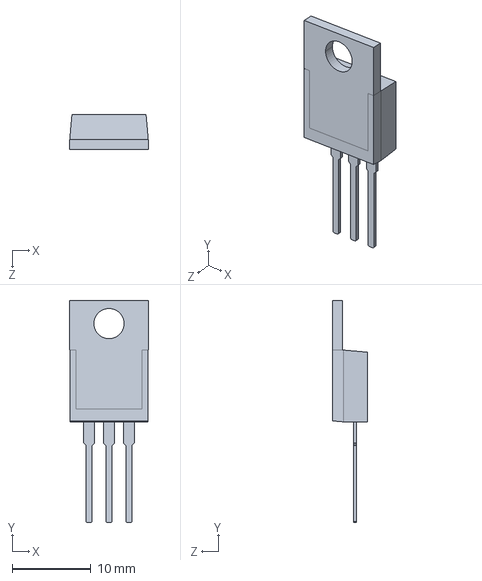
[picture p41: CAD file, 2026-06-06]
deliverables/2_detailed_design/smartlock_mode_jalon2/mosfet.SLDPRT
10.0 x 28.3 x 4.46 mm

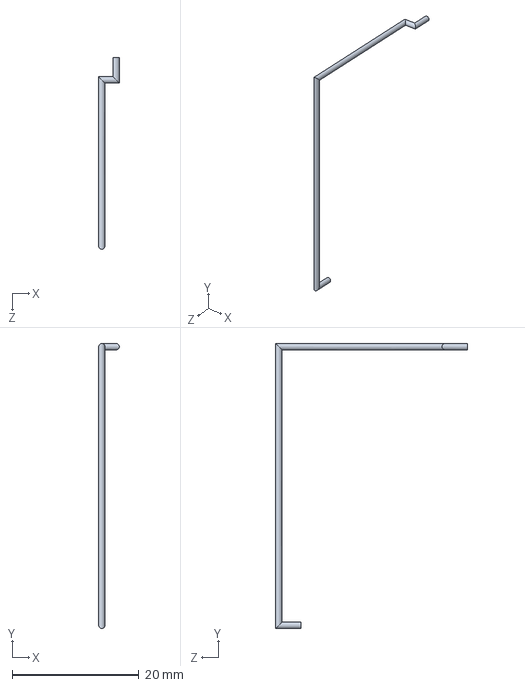
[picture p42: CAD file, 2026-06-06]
deliverables/2_detailed_design/smartlock_mode_jalon2/Cable_Alim_Pn532.SLDPRT
3.28 x 45.1 x 30.3 mm

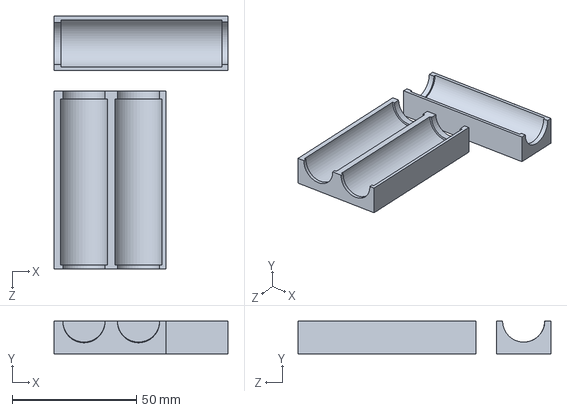
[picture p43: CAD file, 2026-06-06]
deliverables/2_detailed_design/smartlock_mode_jalon2/Support_pile.SLDPRT
70.0 x 13.3 x 102.0 mm

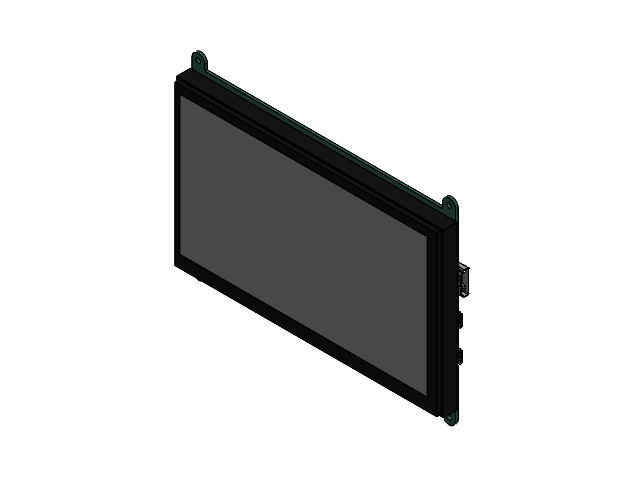
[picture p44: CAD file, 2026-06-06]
deliverables/2_detailed_design/smartlock_mode_jalon2/7 Inch Touch Screen v3.SLDASM
W_X_FCrth 629105150521 Micro USB (Housing).step x 2
W_X_FCrth 629105150521 Micro USB (Inner Shield).step x 2
W_X_FCrth 629105150521 Micro USB (Outer Shield).step x 2
W_X_FCrth 629105150521 Micro USB ( Contact 1,2,4,5).step x 8
W_X_FCrth 629105150521 Micro USB ( Contact 3).step x 2
1.step
2.step
3.step
4.step
Screen Body.step
PCB.step
HDMI molex_0471510001.step

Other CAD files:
deliverables/2_detailed_design/smartlock_mode_jalon2/PN532_NFC_Assembly.SLDASM
deliverables/2_detailed_design/smartlock_mode_jalon2/GX12-2 Plug.SLDASM
deliverables/2_detailed_design/smartlock_mode_jalon2/GX12-2P v2.SLDASM
deliverables/2_detailed_design/smartlock_mode_jalon2/Solenoid_Lock.SLDASM
deliverables/2_detailed_design/smartlock_mode_jalon2/BMS 3S 40A.SLDPRT
deliverables/2_detailed_design/smartlock_mode_jalon2/Cable_Ecran.SLDPRT
deliverables/2_detailed_design/smartlock_mode_jalon2/Cable_SSa.SLDPRT
deliverables/2_detailed_design/smartlock_mode_jalon2/Cable_sole.SLDPRT
deliverables/2_detailed_design/smartlock_mode_jalon2/Cover_Ecran.SLDPRT
deliverables/2_detailed_design/smartlock_mode_jalon2/MC34063AP_DIP8_P2,54_&_Socket_P2,54.SLDASM
deliverables/2_detailed_design/smartlock_mode_jalon2/Pile.SLDPRT
deliverables/2_detailed_design/smartlock_mode_jalon2/SS49E Linear Hall Effect.SLDPRT
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

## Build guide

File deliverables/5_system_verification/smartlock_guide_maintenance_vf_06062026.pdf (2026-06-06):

# SmartLock

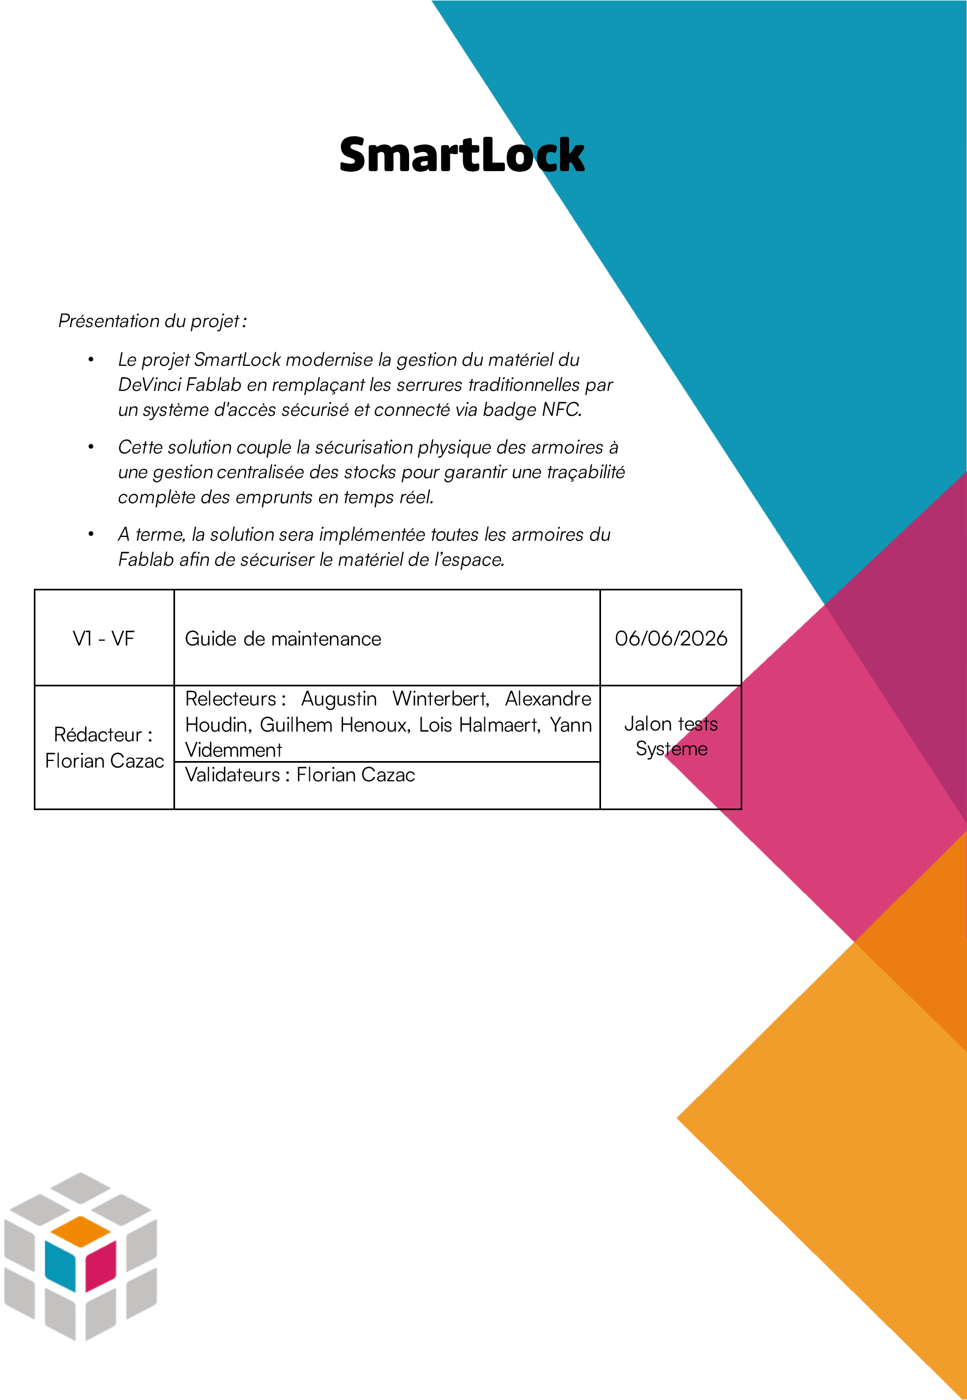
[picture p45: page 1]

V1 - VF | Guide de maintenance | 06/06/2026
Rédacteur : Florian Cazac | Relecteurs : Augustin Winterbert, Alexandre Houdin, Guilhem Henoux, Lois Halmaert, Yann Videmment | Jalon tests Systeme

### Validateurs : Florian Cazac

Présentation du projet :

- Le projet SmartLock modernise la gestion du matériel du DeVinci Fablab en remplaçant les serrures traditionnelles par un système d'accès sécurisé et connecté via badge NFC.
- Cette solution couple la sécurisation physique des armoires à une gestion centralisée des stocks pour garantir une traçabilité complète des emprunts en temps réel.
- A terme, la solution sera implémentée toutes les armoires du Fablab afin de sécuriser le matériel de l’espace.

## 1. Table des matières

## 2. Introduction

Ce guide est destiné à l'équipe technique du DeVinci FabLab et aux successeurs du projet SmartLock . Il décrit l'architecture, les procédures de déploiement, de configuration, de

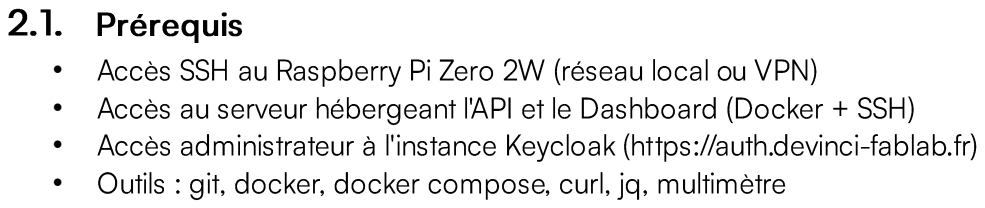
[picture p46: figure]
2.1. Prérequis

- Accès SSH au Raspberry Pi Zero 2W (réseau local ou VPN)
- Accès au serveur hébergeant l'API et le Dashboard (Docker + SSH)
- | Accès administrateur à l'instance Keycloak (https://auth.devinci | -fablab.fr)
- Outils : git, docker, docker compose, curl, jq, multimètre

## 3. Architecture du système

Composant | Technologie | Hébergement | URL / Accès
IHM | Python 3.13 / CustomTkinter | Raspberry Pi Zero 2W | SSH locker@<ip>
API Auth | FastAPI + PostgreSQL | Serveur DeVinci (Docker) | https://api.smartlock.devinci -fablab.fr
Dashboard | SvelteKit / Node.js | Serveur DeVinci (Docker) | https://dashboard.smartlock.devinci -fablab.fr
Keycloak | Keycloak 25+ | Serveur DeVinci (Docker) | https://auth.devinci -fablab.fr

## 4. Inventaire matériel

Composant | Spécification | Rôle
Raspberry Pi Zero 2W | ARM Cortex -A53 1GHz, 512 MB RAM, WiFi 802.11n | Processeur principal, exécute l'IHM Python, contrôle GPIO
Solénoïde 12V | Push -pull 12V DC, ~0.5A, relais 5V sur GPIO 26 (BCM) | Mécanisme de verrouillage physique
Alimentation | 12V 3A (36W), jack 5.5/2.1mm | Source d'énergie principale
Écran tactile 7" | Waveshare 7inch HDMI LCD (H), 1024×600, capacitif 5pts | Interface kiosque, HDMI + USB touch
Convertisseur buck | DC -DC 12V → 5V, 3A max | Alimentation RPi et écran depuis 12V
Lecteur NFC PN532 | I²C / SPI, 13.56 MHz, adresse I²C 0x24 | Lecture des badges NFC utilisateurs
4.1. Brochage — Lecteur NFC PN532 | ↔Raspberry Pi (I²C)
Broche PN532 | Broche RPi (nom) | Pin physique
VCC | 3.3V | Pin 1
GND | GND | Pin 6
SDA | GPIO 2 / SDA | Pin 3
SCL | GPIO 3 / SCL | Pin 5

Vérification : i2cdetect -y 1 → doit afficher l'adresse 0x24.

4.2. Brochage — Relais solénoïde | ↔Raspberry Pi
Broche Relais | Broche RPi (nom) | Pin physique
IN (signal) | GPIO 26 (BCM) | Pin 37
VCC | 5V | Pin 2
GND | GND | Pin 6
Note : GPIO 27 (Pin 13) réservé pour le capteur Hall | — non câblé en version actuelle.

## 5. 4. Déploiement et configuration

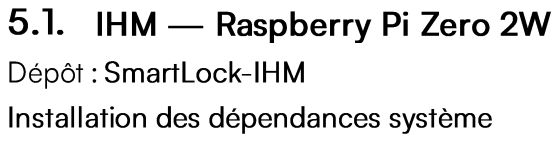
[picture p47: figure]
5.1. IHM — Raspberry Pi Zero 2W; Dépôt : SmartLock - IHM; Installation des dépendances système

sudo apt-get update && sudo apt-get install -y python3-pip python3-tk xorg xinput i2c-tools
pip install customtkinter python-dotenv requests Pillow
pip install adafruit-blinka adafruit-circuitpython-pn532 RPi.GPIO
Configuration de l'environnement

cp .env.example .env
# | Renseigner | : | API_URL, | KEYCLOAK_URL, | KEYCLOAK_REALM, | LOCKER_CLIENT_SECRET,

LOCKER_ID
# Mettre SIMULATION_MODE=False pour la production

Activation I²C

sudo raspi-config → Interface Options → I2C → Enable i2cdetect -y 1 # Vérifier adresse 0x24
Auto -start au boot (~/.xinitrc)

# Copier le fichier .xinitrc du dépôt vers /home/locker/.xinitrc

# Il configure : rotation portrait 90°, calibration touch, boucle de redémarrage

Python

## 5.2. API d'authentification — Serveur Docker

Dépôt : SmartLock - Authentication - Authorization

cp .env.example .env # Renseigner DATABASE_URL, KEYCLOAK_URL, SECRET_KEY docker compose up -d --build
docker compose exec api alembic upgrade head | # Appliquer les migrations
curl https://api.smartlock.devinci-fablab.fr/health | # → {"status":"ok"}

cd docker
cp web/.env.example web/.env # Voir variables ci-dessous

docker compose -f compose.prod.yaml up -d --build
curl http://localhost:3000/health # → {"status":"ok"}
Variables Dashboard requises :

PUBLIC_SMARTLOCK_API_URL=https://api.smartlock.devinci-fablab.frKEYCLOAK_ISSUER=https://auth.devinci-fablab.fr/realms/dev

KEYCLOAK_CLIENT_ID=smartlock-dashboard KEYCLOAK_CLIENT_SECRET=<depuis-admin-keycloak> KEYCLOAK_REDIRECT_URI=https://dashboard.smartlock.devinci-fablab.fr/login/callback

SESSION_SECRET=<openssl rand -hex 32>

## 6. Configuration Keycloak

URL : https://auth.devinci -fablab.fr — Realm : dev (test) ou prod (production)

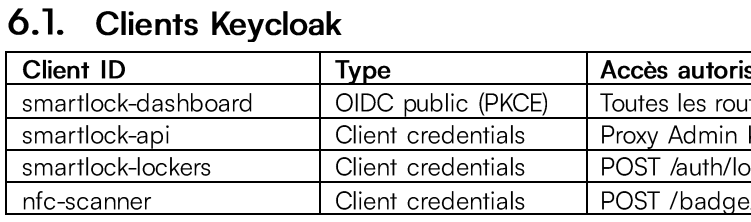
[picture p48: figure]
6.1. Clients Keycloak; Client ID; Type; Accès autorisé

smartlock -dashboard | OIDC public (PKCE) | Toutes les routes Dashboard
smartlock -api | Client credentials | Proxy Admin Keycloak (manage -users)
smartlock -lockers | Client credentials | POST /auth/ locker/{id}/check uniquement
nfc -scanner | Client credentials | POST /badge/scan uniquement

## 6.2. Rôles système

Rôle | Niveau | Description
Admin | T5 | Accès complet — configuration infrastructure
codir / présidence | T4 | Direction — accès audit complet
materialiste | T3 | Responsable du matériel
electronique / textile / 3d | T2 | Responsables de domaine
Bureau | T2 | Bureau de l'association
membre | T0 | Accès de base aux armoires autorisées

## 7. Logs et surveillance

Source | Commande / Chemin | Notes
IHM (Raspberry Pi) | ~/smartlock.log | Truncation auto à 5 MB. Contient : tokens, NFC, GPIO, transactions.
API (Docker) | docker compose logs api | Logs FastAPI/Uvicorn. Filtrer : docker compose logs api | grep ERROR
Da shboard (Docker) | docker compose logs dashboard | Logs SvelteKit/Node. Erreurs de session et d'auth.
Audit métier | GET /access_log/ ou Dashboard /logs | Immuable — ne pas supprimer les entrées.

## 8. Guide de dépannage

Problème | Cause probable | Solution
IHM ne démarre pas au boot | Problème X11 / xinitrc | Vérifier ~/.xinitrc, relancer : startx &
Badge non détecté | I²C mal configuré ou PN532 absent | i2cdetect -y 1 → vérifier 0x24. Contrôler câblage SDA/SCL.
API répond 401 / 403 | Token expiré ou secret incorrect | Vérifier LOCKER_CLIENT_SECRET dans .env. Renouveler dans Keycloak admin.
Solénoïde n'actionne pas | GPIO 26 inactif ou relais défaillant | python -c "import RPi.GPIO as G; G.setmode(G.BCM); G.setup(26,G.OUT); G.output(26,1)"
Écran noir après démarrage | Tension U2 insuffisante (<4.8V) | Mesurer sortie buck. Vérifier connexion HDMI.
Dashboard inaccessible | KEYCLOAK_ISSUER mal configuré | Vérifier .env. Tester GET /health → {"status":"ok"}
Erreur alembic upgrade head | Migration déjà appliquée ou conflit DB | docker compose exec api alembic current
Log ~/smartlock.log trop gros | Pas de rotation automatique | Truncation auto à 5 MB intégrée. Si besoin : truncate -s 0 ~/smartlock.log

## 9. Procédures de mise à jour

## 9.1. IHM (Raspberry Pi)

ssh locker@<adresse-ip-rpi>
cd SmartLock-IHM && git pull origin main
pip install -r requirements.txt --upgrade
sudo reboot # ou pkill -f main.py pour redémarrer sans reboot

## 9.2. API

cd SmartLock-Authentication-Authorization && git pull origin main docker compose build api && docker compose up -d api
docker compose exec api alembic upgrade head # si nouvelles migrations

## 9.3. Dashboard

cd SmartLock-Dashboard/docker && git pull origin main

docker compose -f compose.prod.yaml build dashboard docker compose -f compose.prod.yaml up -d dashboard

## 10. Limitations connues et évolutions futures

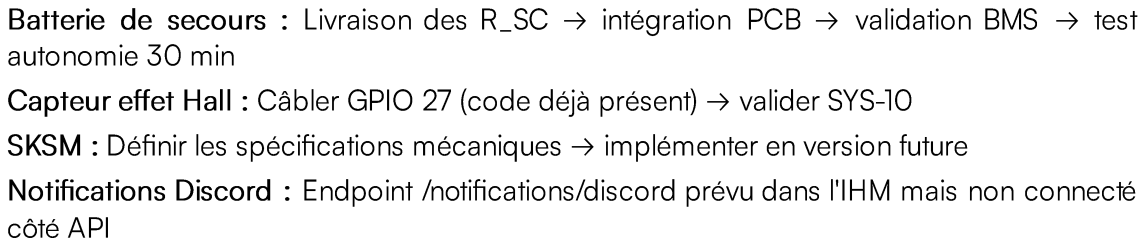
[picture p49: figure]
autonomie 30 min; côté API

Batterie de secours : | Livraison des R_SC → intégration PCB → validation BMS → test
Capteur effet Hall : Câbler GPIO 27 (code déjà présent) → valider SYS | -10
SKSM : Définir les spécifications mécaniques → implémenter en version future Notifications Discord : Endpoint /notifications/discord prévu dans l'IHM mais non connecté

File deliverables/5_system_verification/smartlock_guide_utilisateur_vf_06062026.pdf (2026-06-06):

# SmartLock

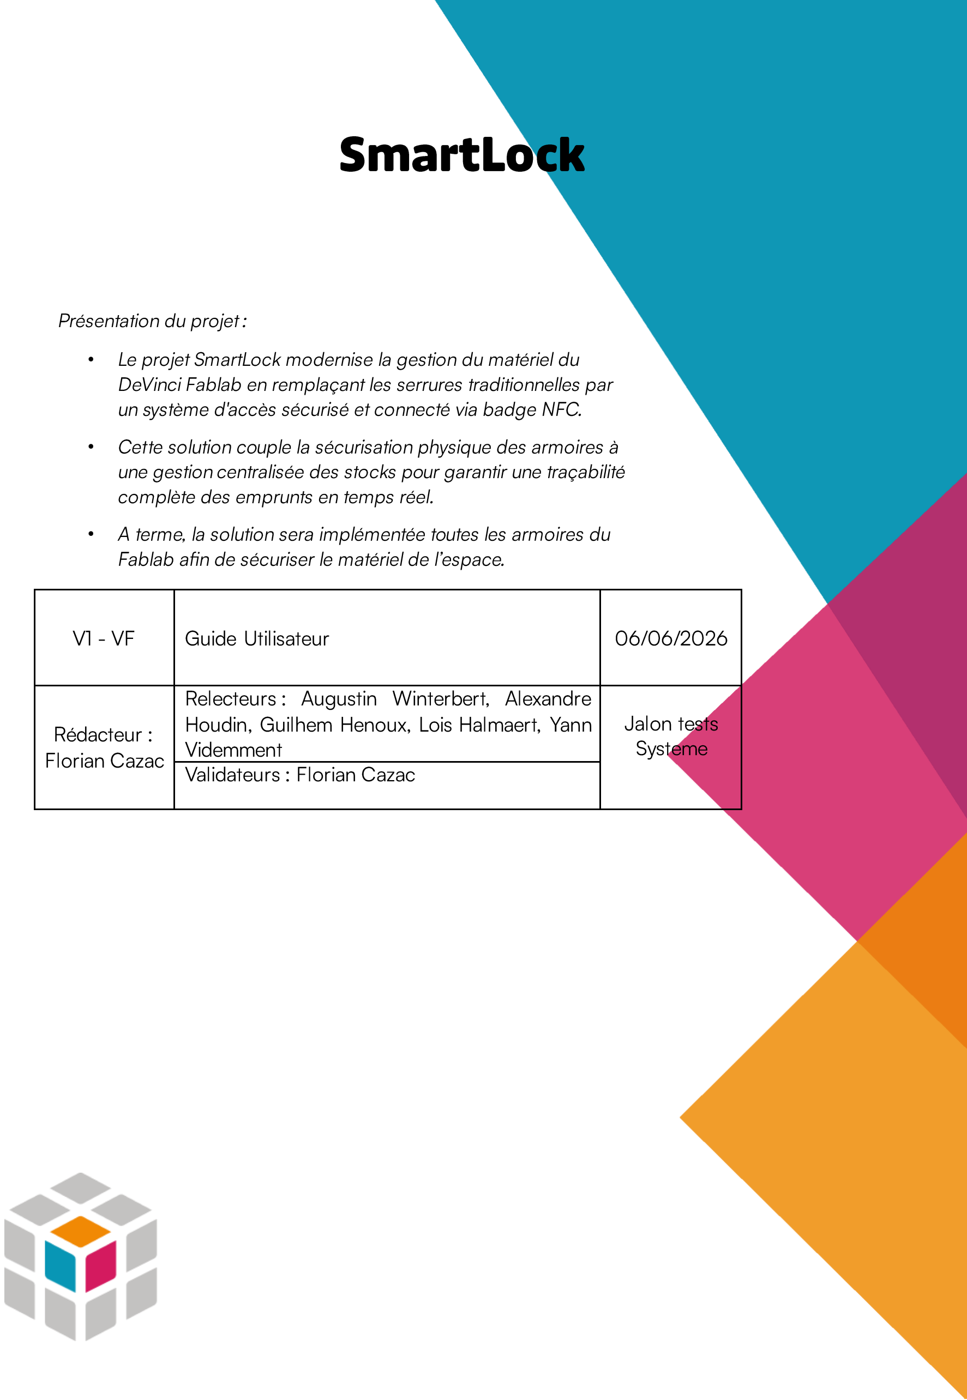
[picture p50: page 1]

V1 - VF | Guide Utilisateur | 06/06/2026
Rédacteur : Florian Cazac | Relecteurs : Augustin Winterbert, Alexandre Houdin, Guilhem Henoux, Lois Halmaert, Yann Videmment | Jalon tests Systeme

Validateurs : Florian Cazac

Présentation du projet :

- Le projet SmartLock modernise la gestion du matériel du DeVinci Fablab en remplaçant les serrures traditionnelles par un système d'accès sécurisé et connecté via badge NFC.
- Cette solution couple la sécurisation physique des armoires à une gestion centralisée des stocks pour garantir une traçabilité complète des emprunts en temps réel.
- A terme, la solution sera implémentée toutes les armoires du Fablab afin de sécuriser le matériel de l’espace.

## 1. Introduction

SmartLock est le système de gestion sécurisée des armoires du DeVinci FabLab. Il permet aux membres d'accéder aux équipements et consommables par simple badge NFC, avec suivi automatique des stocks et journal d'accès. Ce guide s'adresse à deux profils :

- Membres du FabLab : utilisation quotidienne de l'armoire connectée
- Administrateurs : gestion du système via le tableau de bord web

## 2. PARTIE 1 — Guide du membre

Prérequis : votre badge NFC doit avoir été enregistré par un administrateur et vous devez disposer d'une permission d'accès sur l'armoire concernée.

À l'état initial, l'écran invite à présenter le badge. Si aucune interaction n'est détectée pendant 2 minutes, l'écran repasse en veille automatiquement.

### 2.2. S'authentifier et ouvrir l'armoire

### 1. Présenter votre badge NFC : Approchez votre badge à moins de 5 cm du lecteur. Votre

prénom s'affiche en moins de 2 secondes.
2. Parcourir le catalogue : Naviguez dans les catégories (ex. : Impression 3D, Électronique…). Articles indisponibles = grisés. Stock bas = surlignés en orange.
3. Sélectionner vos articles : Touchez un article pour ajuster la quantité (boutons + et −). Ajoutez au panier, puis continuez ou accédez directement au panier.
4. Valider le panier : Vérifiez articles et quantités. Touchez « Valider & Ouvrir ». Si une quantité
dépasse le stock disponible, la ligne apparaît en rouge | — corrigez -la.
5. Récupérer vos articles : | L'armoire s'ouvre (clic audible). Récupérez vos articles et refermez
l'armoire.
6. Confirmer la clôture : L'écran demande si tout s'est bien passé. Répondez honnêtement — cela met à jour les stocks. En cas de problème, utilisez le bouton « Signaler ».

Sur l'écran de clôture, le bouton « Signaler un problème » propose :

- Porte bloquée — l'armoire ne s'est pas ouverte ou ne se referme pas
- Stock incorrect — la quantité affichée ne correspond pas à la réalité
- Article abîmé — un article est endommagé
- Retour panier — vous souhaitez corriger votre commande avant la clôture

### 2.4. Timers d'inactivité

Écran | Délai avant retour à l'accueil
Écran d'accueil (avant badgeage) | 2 minutes
Navigation / Sélection / Panier | 90 secondes
Armoire ouverte (alerte) | 10 minutes → alerte envoyée

R : Vérifiez que votre badge a été enregistré par un admin. Contactez le responsable pour vérifier vos permissions sur cette armoire.

Q : L'armoire ne s'ouvre pas malgré l'accès accordé.
R : Signalez le problème via l'écran. Contactez un administrateur ou un responsable

Q : Un article est affiché en stock mais absent physiquement.
R : Signalez via l'écran de clôture → « Stock incorrect ».

Q : Je me suis trompé dans la quantité après validation.
R : Sur l'écran de clôture, utilisez « Retour panier » pour corriger votre commande.

## 3. PARTIE 2 — Guide de l'administrateur

Cette partie s'adresse aux administrateurs du FabLab qui utilisent le tableau de bord SmartLock pour gérer les utilisateurs, les armoires, les stocks et consulter les journaux.

URL : https://dashboard.smartlock.devinci -fablab.fr (https://dashboard.smartlock.devinci-fablab.fr/)

La connexion utilise Keycloak (identifiants DeVinci). Les rôles T2+ (Bureau, Responsables, Direction, Admin) nécessitent un code OTP (type Google Authenticator). Les membres T0/T1

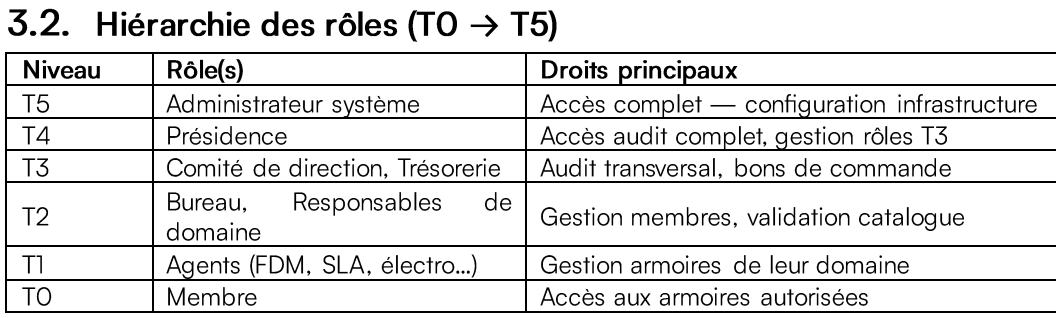
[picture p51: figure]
3.2. Hiérarchie des rôles (T0 → T5); Niveau; Rôle(s); Droits principaux; Membre; Accès aux armoires autorisées

T5 | Administrateur système | Accès complet — configuration infrastructure
T4 | Présidence | Accès audit complet, gestion rôles T3
T3 | Comité de direction, Trésorerie | Audit transversal, bons de commande
T2 | Bureau, Responsables de domaine | Gestion membres, validation catalogue
T1 | Agents (FDM, SLA, électro…) | Gestion armoires de leur domaine

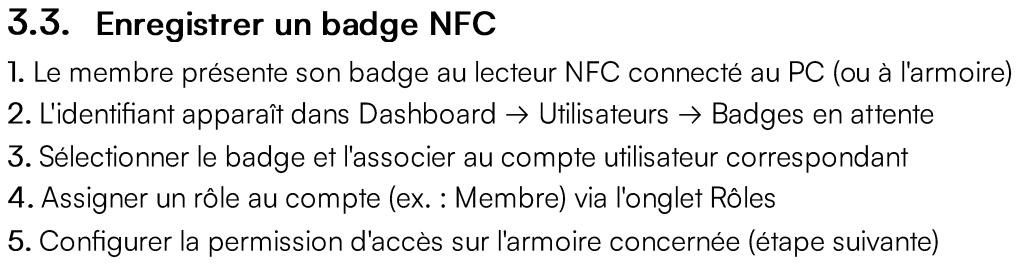
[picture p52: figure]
3.3. Enregistrer un badge NFC

1. Le membre présente son badge au lecteur NFC connecté au PC (ou à l'armoire) 2. L'identifiant apparaît dans Dashboard → Utilisateurs → Badges en attente 3. Sélectionner le badge et l'associer au compte utilisateur correspondant 4. Assigner un rôle au compte (ex. : Membre) via l'onglet Rôles 5. Configurer la permission d'accès sur l'armoire concernée (étape suivante)

Dashboard → Armoires → Sélectionner l'armoire → onglet Permissions → choisir le rôle et le

can_view | Voir le contenu de l'armoire (lecture seule)
can_open | Ouvrir l'armoire, ajouter/retirer des articles, consulter les logs de cette armoire
can_edit | Modifier le catalogue, les descriptions, les seuils de stock bas
Accès temporaire : | renseigner le champ | valid_until pour définir une date d'expiration
automatique.

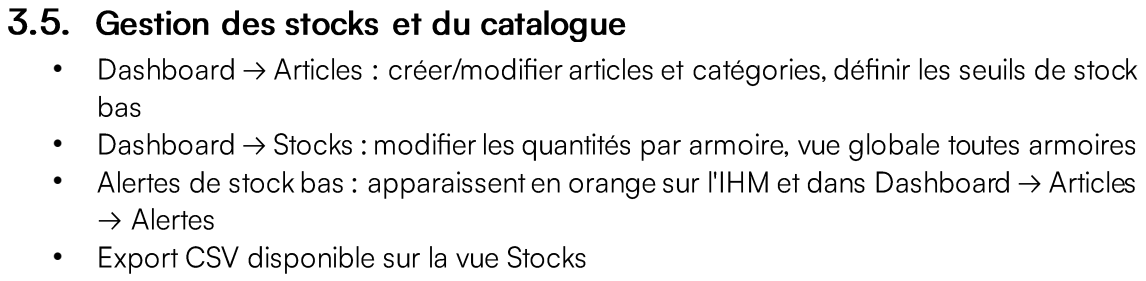
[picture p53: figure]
3.5. Gestion des stocks et du catalogue; bas; → Alertes

- Dashboard → Articles : créer/modifier articles et catégories, définir les seuils de stock
- Dashboard → Stocks : modifier les quantités par armoire, vue globale toutes armoires
- Alertes de stock bas : apparaissent en orange sur l'IHM et dans Dashboard → Articles
- Export CSV disponible sur la vue Stocks

Dashboard → Logs. Journal immuable de toutes les tentatives d'accès (accordées et refusées). Filtrer par armoire, date, résultat. Export CSV disponible.

- Accès complet (toutes armoires) : rôles codir, présidence, admin système
- Accès restreint (une armoire) : tout utilisateur avec can_open sur cette armoire
- | Les journaux ne peuvent pas être modifiés ou supprimés | - preuve d'audit

### 3.7. Gestion des rôles personnalisés

- | Dashboard → Rôles : créer un rôle (nom, label FR, niveau T0 | - T5)
- Assigner des capacités spécifiques (ex. : manage_stock_thresholds, validate_catalog)
- Activer le flag is_manager pour permettre à ce rôle de gérer d'autres membres
- Assigner le rôle à des utilisateurs via Utilisateurs → onglet Rôles

Q : Un utilisateur ne peut pas accéder à une armoire pourtant autorisée.
R : 1) Badge enregistré ? 2) Compte actif (non révoqué) ? 3) Permission can_open configurée pour son rôle sur cette armoire ? 4) Permission non expirée (valid_until) ?

Q : Comment voir qui a ouvert l'armoire ce matin ?
R : Dashboard → Logs → Filtrer par armoire et par date → résultat : allowed=true.

Q : Le tableau de bord n'affiche plus les données.
R : Vérifier que l'API est accessible (GET /health). Si le token a expiré, se déconnecter et se

R : Armoires → Armoire → Permissions → can_open pour le rôle + renseigner valid_until.

R : Dashboard → Articles → Alertes. Mettre à jour les stocks ou déclencher une commande.

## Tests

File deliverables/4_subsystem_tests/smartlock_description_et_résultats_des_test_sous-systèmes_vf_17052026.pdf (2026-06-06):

# SmartLock

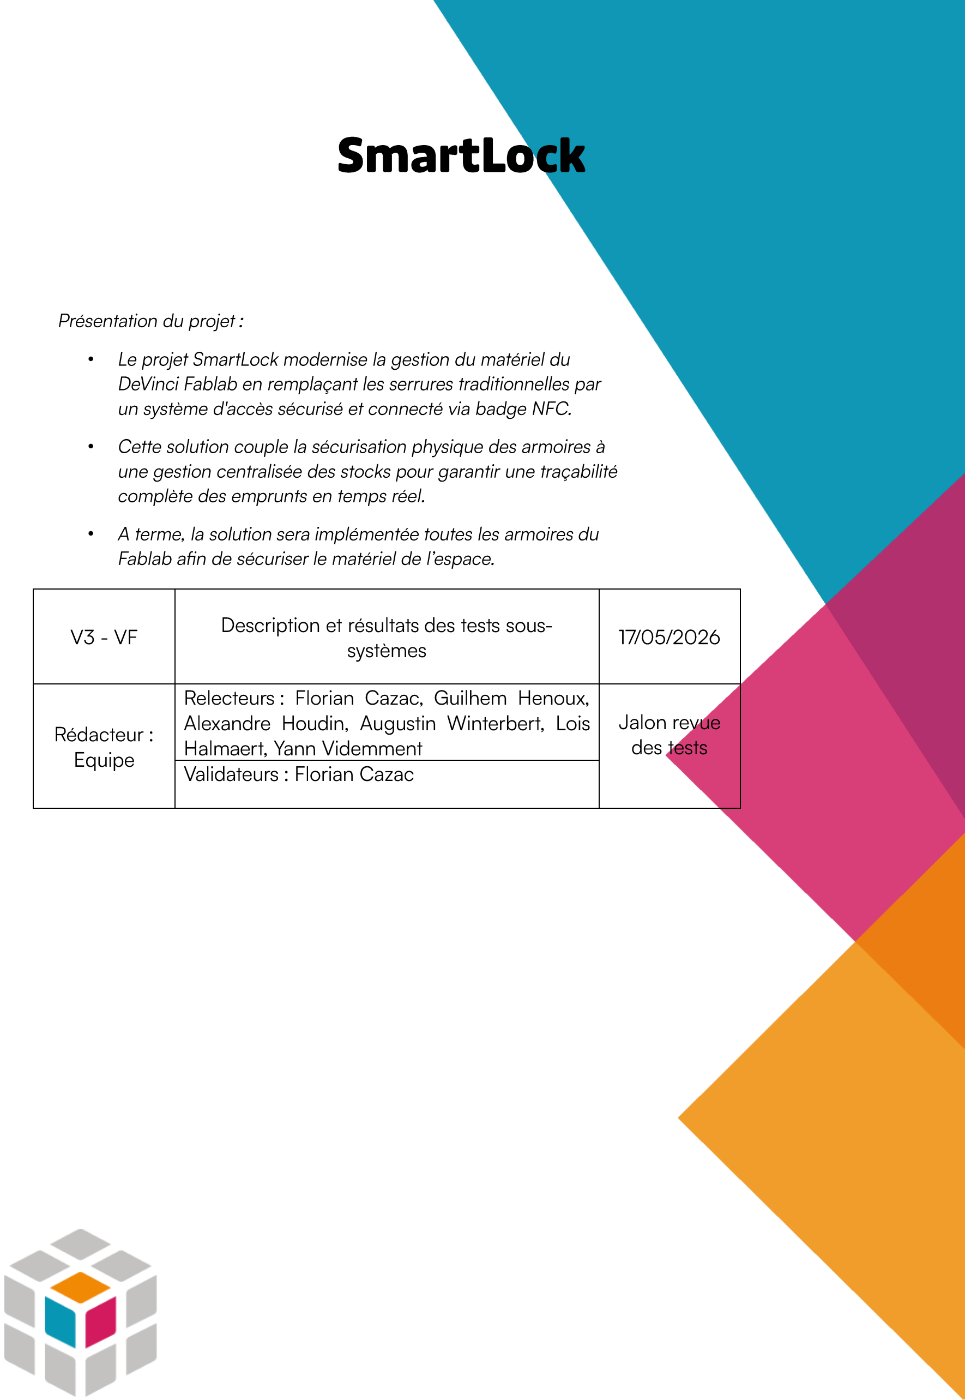
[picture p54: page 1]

V3 - VF | Description et résultat s des tests sous-systèmes | 17/05/2026
Rédacteur : Equipe | Relecteur s : Florian Cazac , Guilhem Henoux , Alexandre Houdin , Augustin Winterber t, Lois Halmaert, Yann Videmment | Jalon revue des tests

Validateurs : Florian Cazac

Présentation du projet :

- Le projet SmartLock modernise la gestion du matériel du DeVinci Fablab en remplaçant les serrures traditionnelles par un système d'accès sécurisé et connecté via badge NFC.
- Cette solution couple la sécurisation physique des armoires à une gestion centralisée des stocks pour garantir une traçabilité complète des emprunts en temps réel.
- A terme, la solution sera implémentée toutes les armoires du Fablab afin de sécuriser le matériel de l’espace.

## Table des matières

## 1. Introduction

Ce document présente les descriptions et résultats des tests réalisés sur les différents sous-systèmes du projet SmartLock. SmartLock est une serrure connectée et autonome destinée à sécuriser les armoires de l'association DVFL et à gérer une base de donné es facilitant la gestion des stocks. Le système embarque une interface utilisateur (écran tactile + RFID), un microcontrôleur (Raspberry Pi Zero 2W), un verrou
électromagnétique (solénoïde 12V) et une chaîne d'alimentation complète incluant une batterie de secours 3S Li -Ion avec BMS.

### 1.1. Architecture générale du système

Le PCB custom (version V4) intègre les sous -systèmes suivants, d'après le schéma

- Alimentation secteur : adaptateur AC/DC 220V → 12V (J8)
- 4 régulateurs DC -DC à base de MC34063ADR (U1 à U4) : 12V→5V, 11,1V→5V, 11,1V→12V, 12V→12,6V
- BMS 3S (J10) + pack 3×18650 Samsung 25R pour l'alimentation de secours
- Raspberry Pi Zero 2W (U10) - cerveau du système
- Lecteur RFID/NFC PN532 (I²C via GPIO2/SDA, GPIO3/SCL)
- Écran 7" HDMI capacitif Waveshare 1024×600 (U20)
- Solénoïde 12V (L10) - actionneur du verrou
- Capteur à effet Hall A1101xLH (U15) - détection position verrou
- Module BIGTREETECH SKSM V1.0 (J2) - sauvegarde données
- LEDs de signalisation (D20, D21), buzzer (BZ2), interrupteur de protection (SW1), fusible 3,15A (F1)
- MOSFET N - channel (Q1) - commande du solénoïde
- Optocoupleur LTV -817 (U5) - isolation galvanique

## 2. Sous -système : PCB custom - Assemblage et soudure

Responsable : Guilhem Henoux

### 2.1. Description

Après conception du schéma électronique sous KiCad et routage du PCB, la carte a
été assemblée manuellement. Il s'agissait d'un premier assemblage SMD (Surface Mount Device), impliquant un apprentissage progressif des techniques de soudure fine. Les compos ants concernés sont les régulateurs MC34063ADR, condensateurs, résistances et inductances CMS (0402/0603/0805) ainsi que les diodes Schottky 1N5822. La durée estimée a été de 6 à 10 heures, principalement en raison de la courbe d'apprentissage.

### 2.2. Procédure

- Application de pâte à souder sur les pastilles CMS
- Placement des composants SMD et passage sur plaque chauffante
- Soudure des composants traversants (JST)
- Inspection visuelle et contrôle de continuité au multimètre

Pour certains composants plus grands comme les diodes, la soudure a été réalisée directement à l'étain sans pâte à souder.

### 2.3. Résultats et observations

Le PCB est fonctionnel : aucun court | - circuit, toutes les pistes sont continues, et
l'intégration est conforme au layout KiCad. Un défaut mineur subsiste | — un câble devra
relier le pin 12V au pin 4 de l'optocoupleur. Des soudures plus robustes (remplacement des headers par des soudures directes) sont prévues en fin de projet.

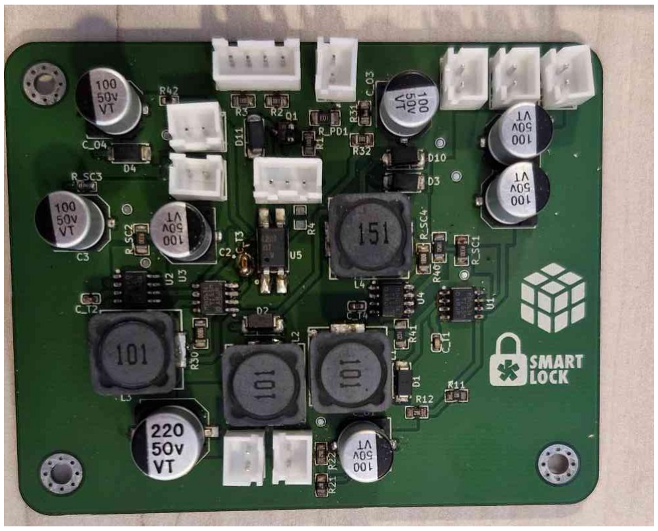
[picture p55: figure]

Figure 1PCB assemblé

## 3. Sous -système : Régulateurs DC -DC (MC34063ADR)

Responsable : Guilhem Henoux

### 3.1. Description

Le PCB embarque quatre régulateurs DC | -DC basés sur le MC34063ADR (U1 à U4), un
convertisseur DC -DC monolithique capable de fonctionner en step | -down, step -up ou
inverting. Chaque régulateur est dimensionné pour une tension de sortie spécifique, calculée par le pont diviseur résistif R1/R2 et les composants passifs associés.

### 3.2. Configurations des 4 régulateurs

Le PCB embarque quatre régulateurs aux rôles distincts. U1 et U2 sont tous deux configurés en mode buck avec une sortie 5V à ~1A : U1 est alimenté depuis le secteur (12V) et alimente la Raspberry Pi et les périphériques en fonctionnement normal, tandis que U2 prend le relais depuis la batterie (11,1V) en cas de coupure secteur. U3 est configuré en boost depuis la batterie (11,1V → 12V, ~0,6A) pour alimenter le solénoïde en mode secours. Enfin, U4 est un boost dédié à la charge du pack batteries (12V → 12,6V, ~250mA).

### 3.3. Problème identifié : limitation du courant de sortie

Lors des tests avec la Raspberry Pi 4, une chute de tension significative a été mesurée
à la connexion de l'écran : 4,94V sans charge, 4,82V sous charge Raspberry Pi 4, et
l'écran ne s'allumait plus. Avec la Raspberry Pi Zero 2W, l'écran s'allume faiblemen t mais

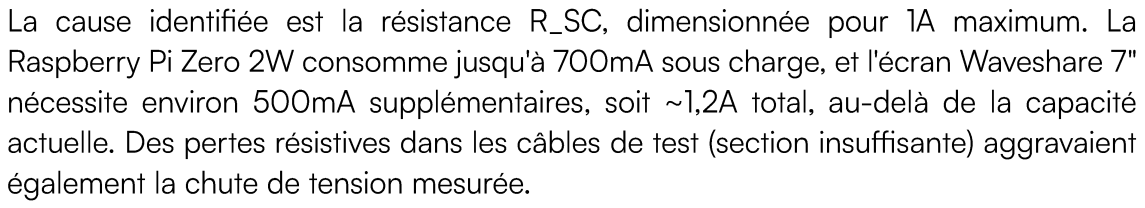
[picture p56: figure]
également la chute de tension mesurée.

La cause identifiée est la résistance R_SC, dimensionnée pour 1A maximum. La
Raspberry Pi Zero 2W consomme jusqu'à 700mA sous charge, et l'écran Waveshare 7" nécessite environ 500mA supplémentaires, soit ~1,2A total , au-delà de la capacité actuelle. Des pertes résistives dans les câbles de test (section insuffisante) aggravaient

### 3.4. Correction prévue

Remplacement des 4 résistances R_SC (R_SC1 à R_SC4) pour doubler le courant de sortie autorisé (~2A), avec ajustement de deux résistances en sortie de régulateur pour corriger légèrement la tension. Les nouvelles valeurs sont en cours
d'approvisionnement ( Mouser/LCSC). Les valeurs recherchées n'étaient pas disponibles en stock DVB ou IFT lors de la recherche du 06/05/2026.

## 4. Sous -système : BMS 3S et pack batteries Li -Ion

Responsable : Guilhem Henoux

### 4.1. Description

Le système embarque une batterie de secours composée de 3 cellules 18650 Samsung INR25R (2500mAh, 20A max en décharge) montées en série, formant un pack 3S
(tension nominale 11,1V, tension max 12,6V). La gestion est assurée par un BMS 3S (J10, Fasizi) qui protège les cellules contre la surcharge, la sous -tension et les courts - circuits, et assure l'équilibrage. La charge s'effectue via le régulateur U4 (12V → 12,6V, ~250mA)
et la décharge via les régulateurs U2 (→5V) et U3 (→12V).

### 4.2. Résultats et observations

Le BMS a été soudé et testé de manière isolée avec succès : fonctionnement confirmé
en charge (tension cellules < 4,2V) et en décharge à petit courant. L'intégration
complète au circuit PCB est prévue après correction du sous | -système régulateurs
(remplacem ent des R_SC). Cette précaution est volontaire : intégrer un pack batteries dans un circuit non encore stabilisé en courant présente des risques, et il est préférable de procéder méthodiquement .

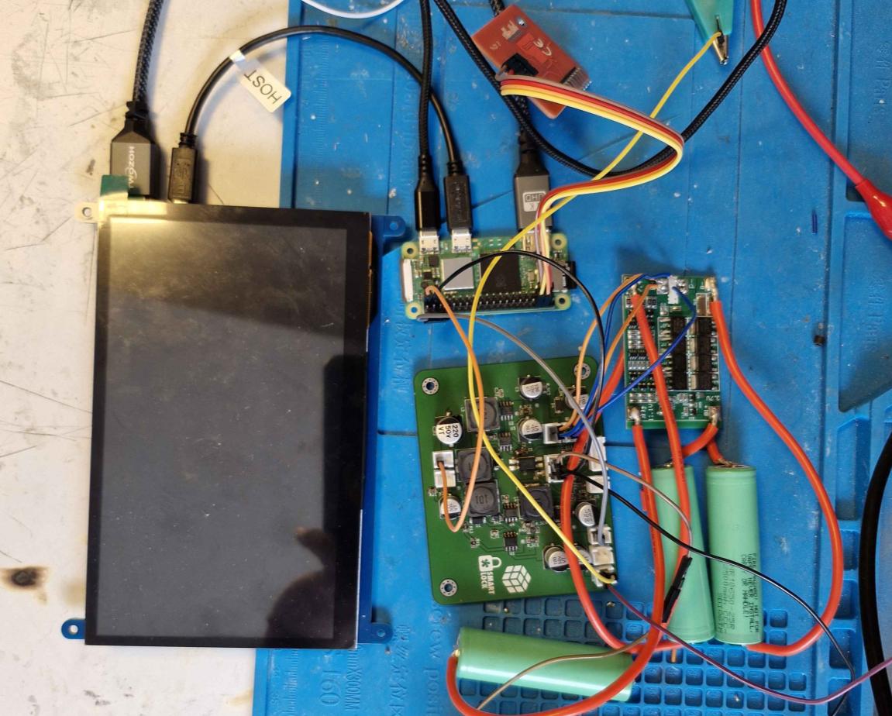
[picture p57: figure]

Figure 2 Test de BMS

## 5. Sous -système : Intégration mécanique

Responsable : Alexandre Houdin

### 5.1. Description

Cette phase couvre l'intégration physique de l'ensemble des composants (PCB, écran, solénoïde, câbles, BMS, pack batteries) dans le boîtier mécanique du SmartLock. L'objectif est de vérifier que la modélisation 3D permet d'accueillir tous les éléments sans contrainte, et d'identifier les ajustements nécessaires.

### 5.2. Résultats et observations

Le test d'intégration a permis de valider le principe d'assemblage général. Cependant, plusieurs points de la modélisation 3D devront être modifiés pour accommoder l'ensemble des câbles et des composants dans les contraintes réelles du boîtier. Les zones d e conflit identifiées sont en cours d'intégration dans le modèle CAO.

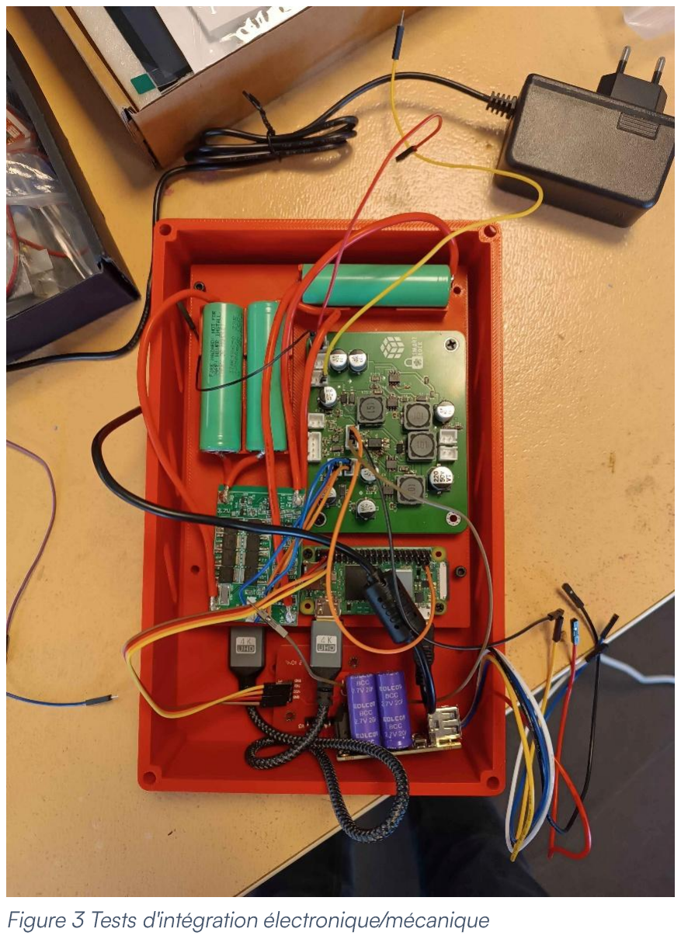
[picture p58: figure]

Figure 3 Tests d' intégration électronique /mécanique

## 6. Sous -système : API et Database

Responsable : Florian Cazac

6.1. Description

L’API REST constitue le cœur logiciel du système SmartLock. Développée avec le framework FastAPI (Python 3.12), elle assure la gestion centralisée des accès aux casiers, de l’inventaire du stock, et la traçabilité de l’ensemble des tentatives d’accès. Elle s’interface avec Keycloak (serveur d’identité open -source) pour l’authentification par jetons J WT et la gestion des rôles utilisateurs, et s’appuie sur une base de données PostgreSQL pour la persistance des données.

L’API sert deux types de clients :

Le tableau de bord web (Svelte SPA) : interface d’administration pour la gestion des casiers, des permissions, des utilisateurs et du stock
Le terminal Raspberry Pi : vérification d’accès en temps réel lors d’un badgeage

Le déploiement est conteneurisé via Docker Compose, avec exécution automatique des migrations de base de données au démarrage.

6.2. Architecture et routes principales
L’API est structurée en plusieurs modules fonctionnels indépendants | :
Module | Route | Rôle
Authentification NFC | /auth | Vérification d’accès carte → casier
Casiers | /lockers | CRUD de l’inventaire des casiers
Permissions | /permissions | Association rôle → casier avec niveau d’accès
Utilisateurs | /users | Proxy Keycloak + cycle de vie des comptes
Rôles | /roles | Gestion des rôles avec hiérarchie de niveaux
Badges NFC | /badge | Enregistrement et association des cartes NFC
Logs d’accès | /logs | Journal d’audit des tentatives d’accès
Stock | /items, /categories, /stock | Gestion du catalogue et des niveaux de stock

Flux principal de vérification d’accès (POST /auth/locker/{id}/check) :

Le terminal Raspberry Pi envoie l’identifiant brut de la carte NFC à l’API L’API hache l’identifiant (SHA -256) et interroge Keycloak pour identifier l’utilisateur correspondant
L’API vérifie que le compte utilisateur est actif (non révoqué)
Les rôles effectifs de l’utilisateur sont récupérés depuis Keycloak
La base de données est interrogée pour déterminer si un rôle de l’utilisateur dispose d’une permission sur le casier demandé
L’API retourne une décision (allowed : true/false) avec le niveau de permission effectif (can_view, can_open, can_edit)
La tentative d’accès (accordée ou refusée, avec motif) est enregistrée dans le journal d’audit

Modèle de permission : Les permissions sont stockées dans la table locker_permissions sous la forme d’une association rôle → casier → niveau. La
hiérarchie can_view | < can_open | < can_edit est résolue dynamiquement. Les
permissions peuvent être limitées dans le temps via un champ | valid_until.
6.3. Tests réalisés

Les tests ont été conduits sur trois niveaux.

Tests automatisés (pytest) - 87 cas de test - Voir Figure

Fichier de test | Cas | Couverture
test_routes.py | 55 | Endpoints REST, gardes RBAC, codes HTTP
test_roles_crud.py | 9 | CRUD des rôles, hiérarchie de niveaux
test_crud_role.py | 9 | Opérations base de données sur les rôles
test_users_lifecycle.py | 7 | Révocation, restauration, suppression de compte
test_keycloak_admin.py | 3 | Client Keycloak asynchrone (appels simulés)
test_roles_model.py | 2 | Modèle de rôle (champs, unicité)
test_permission_model.py | 2 | Modèle de permission (champs, contrainte unique)

Infrastructure de test : base SQLite en mémoire par test, appels Keycloak simulés via AsyncMock, limitation de débit désactivée, fixtures de clients par rôle (admin, codir, membre, nfc -scanner, raspberry pi).

Tests d’intégration Keycloak

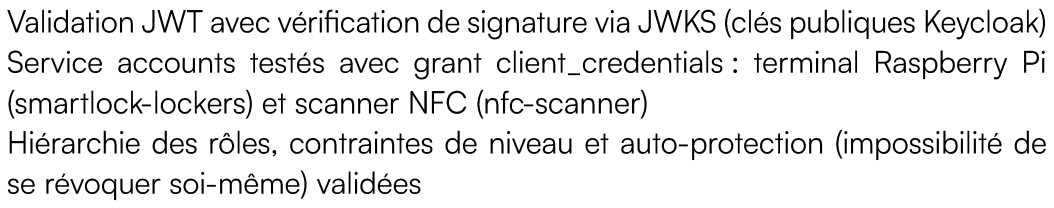
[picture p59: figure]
se révoquer soi -même) validées

Validation JWT avec vérification de signature via JWKS (clés publiques Keycloak) Service accounts testés avec grant client_credentials : terminal Raspberry Pi (smartlock -lockers) et scanner NFC (nfc -scanner)
Hiérarchie des rôles, contraintes de niveau et auto -protection (impossibilité de

Tests end -to-end avec le Raspberry Pi

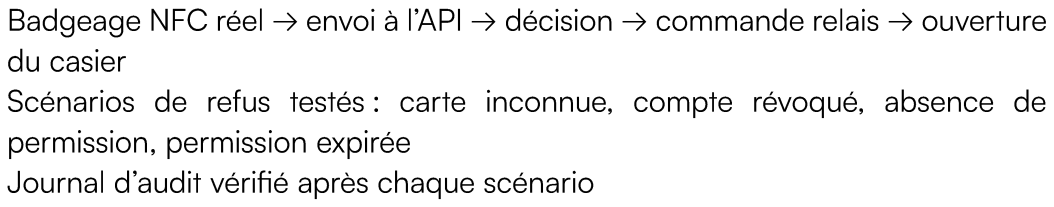
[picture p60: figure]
du casier; permission, permission expirée

Badgeage NFC réel → envoi à l’API → décision → commande relais → ouverture

Scénarios de refus testés : carte inconnue, compte révoqué, absence de

Journal d’audit vérifié après chaque scénario

6.4. Résultats et observations

87/87 tests automatisés passants, aucun échec
L’API est opérationnelle et connectée à l’IHM du terminal Raspberry Pi
Le flux NFC complet (badgeage → décision → ouverture) fonctionne en
conditions réelles
La sécurité repose sur le hachage de l’identifiant NFC côté serveur | : aucun
secret ne transite entre le terminal et l’API
Un mécanisme de mise en cache des tokens de service account (30 secondes) limite la charge sur Keycloak lors de badgeages fréquents

Voir Annexe

## 7. Sous -système : Interface Homme -Machine (IHM)

Responsable : Loïs Halmaert

### 7.1. Description

L'IHM est développée en Python avec la librairie CustomTkinter et fonctionne sur un Raspberry Pi 4 équipé d'un écran tactile LCD 1024×600. Elle gère l'ensemble des interactions utilisateur : badgeage NFC, navigation dans les stocks, sélection d'articles, validation et clôture de session. L'interface est entièrement r esponsive — toutes les dimensions sont calculées dynamiquement à partir de la résolution cible (g.SW = 1024,
g.SH = 600) | — et un design system cohérent a été appliqué sur l'ensemble des vues
(corner_radius uniforme, palette de couleurs unifiée, typographie | s cohérentes).

### 7.2. Architecture des vues

- home_view.py : écran d'accueil avec badgeage NFC automatique
- navigation_view.py : menu principal (Tendances, Filaments, Électronique)
- selection_couleur.py : choix de la couleur pour les filaments
- ecran_selection.py : sélection de la quantité avec affichage du stock
- vue_panier.py : récapitulatif des articles sélectionnés
- validation_finale.py : confirmation de la commande
- acces_physique.py : écran d'ouverture de l'armoire
- ecran_cloture.py : bilan de session avec signalement de problèmes

Un module timer_manager.py centralise la gestion de l'inactivité : 30 secondes sur l'écran d'accueil entraînent la fermeture du programme, 90 secondes sur les autres écrans un retour à l'accueil, et 10 minutes sur l'écran d'accès physique déclenchent une

### 7.3. Intégration API REST et lecture NFC

L'IHM est connectée à l'API REST SmartLock (api.smartlock.devinci -fablab.fr), sécurisée par Keycloak. Les fonctionnalités implémentées couvrent l'authentification via client_credentials avec renouvellement automatique du token, l'identification badge (POST /auth/locker/{id}/check), la récupération des stocks (GET /lockers/{id}/stock), l'enregistrement des transactions (PUT /stock/{id}), la commande GPIO directe pour l'ouverture du relais, et la détection de fermeture de porte par polling GPIO toutes les
2 s econdes.

La lecture NFC est automatique : un thread démarre en arrière -plan dès l'affichage de l'écran d'accueil et attend le badge sans intervention de l'utilisateur. Un flag SIMULATION_MODE permet de basculer entre mode simulé (données fictives, pas de réseau) et mode réel sans modifier la logique de l'IHM.

### 7.4. Résultats

Les tests en mode réel ont confirmé le bon fonctionnement de l'ensemble : démarrage de l'IHM sur Raspberry Pi validé, responsive vérifié sur 6 résolutions différentes, authentification Keycloak fonctionnelle avec renouvellement automatique, badge NFC physique détecté et transmis à l'API, stocks chargés depuis la base de données réelle, transactions enregistrées correctement, et timers d'inactivité opérationnels. Le déploiement via SSH/scp a nécessité des corrections spécifiques à l'environnement Pi (rendu d es emojis, affichage des images, lancement automatique au démarrage).

## 8. Bilan et prochaines étapes

### 8.1. Synthèse

À ce stade du projet, trois sous -systèmes sont entièrement validés. Le PCB est fonctionnel, les soudures ont été vérifiées et l'IHM est opérationnelle et connectée à l'API et au lecteur NFC. Quatre sous -systèmes sont en cours de finalisation : les régulate urs DC -DC (remplacement des R_SC prévu), le BMS et le pack batteries (testés isolément, intégration PCB à faire), l'écran HDMI 7" (bloqué par la limitation de courant des régulateurs) et l'intégration mécanique (assemblage validé, modélisation CAO à ajuster). Les sous -systèmes restants — lecteur RFID PN532, capteur Hall, solénoïde + MOSFET et module SKSM — n'ont pas encore été testés sur le PCB complet et constituent les prochaines priorités, le solénoïde étant le plus critique.

### 8.2. Actions immédiates

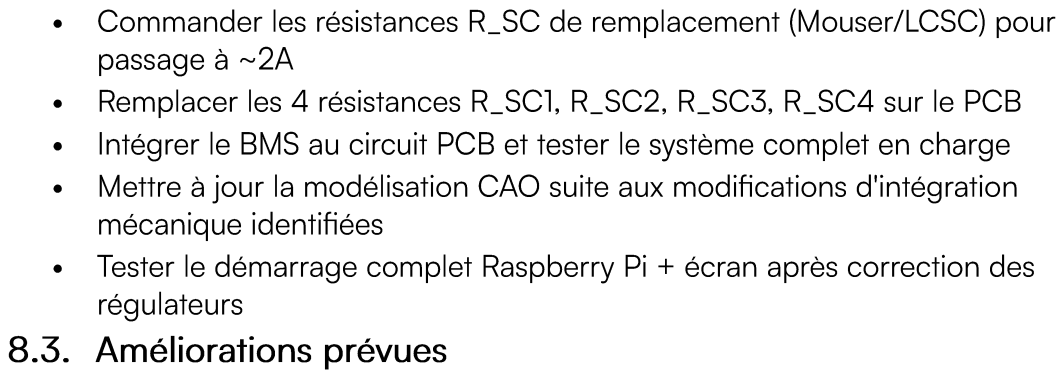
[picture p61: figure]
passage à ~2A; mécanique identifiées; régulateurs 8.3. Améliorations prévues

- Commander les résistances R_SC de remplacement (Mouser/LCSC) pour
- Remplacer les 4 résistances R_SC1, R_SC2, R_SC3, R_SC4 sur le PCB
- Intégrer le BMS au circuit PCB et tester le système complet en charge
- Mettre à jour la modélisation CAO suite aux modifications d'intégration
- Tester le démarrage complet Raspberry Pi + écran après correction des
- Remplacement des headers par des soudures directes pour améliorer la
- Utilisation de câbles de section suffisante pour limiter les pertes résistives
- Repositionnement définitif de l'écran et du solénoïde dans le boîtier

## 9. Annexes

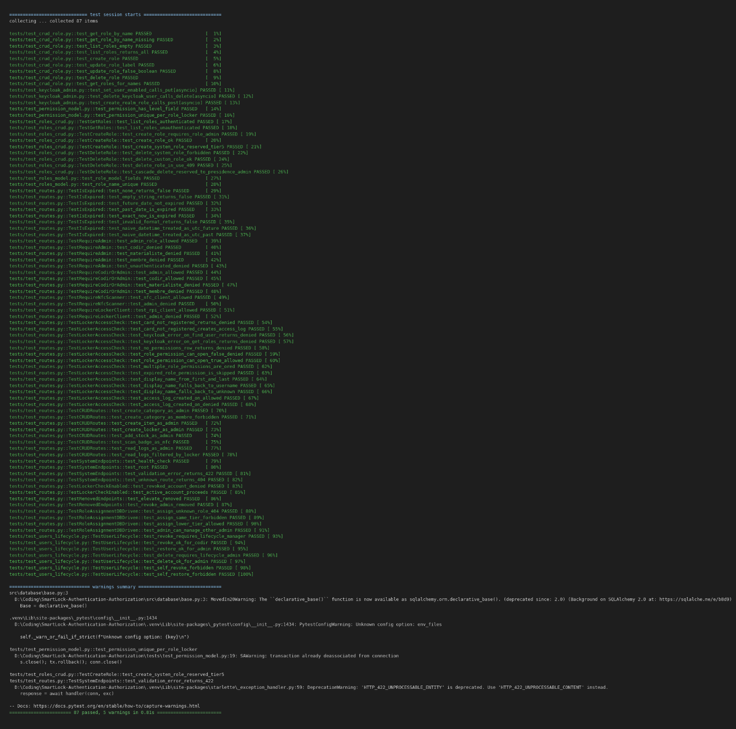
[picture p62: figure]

Figure 4 Resultats des tests de l'API

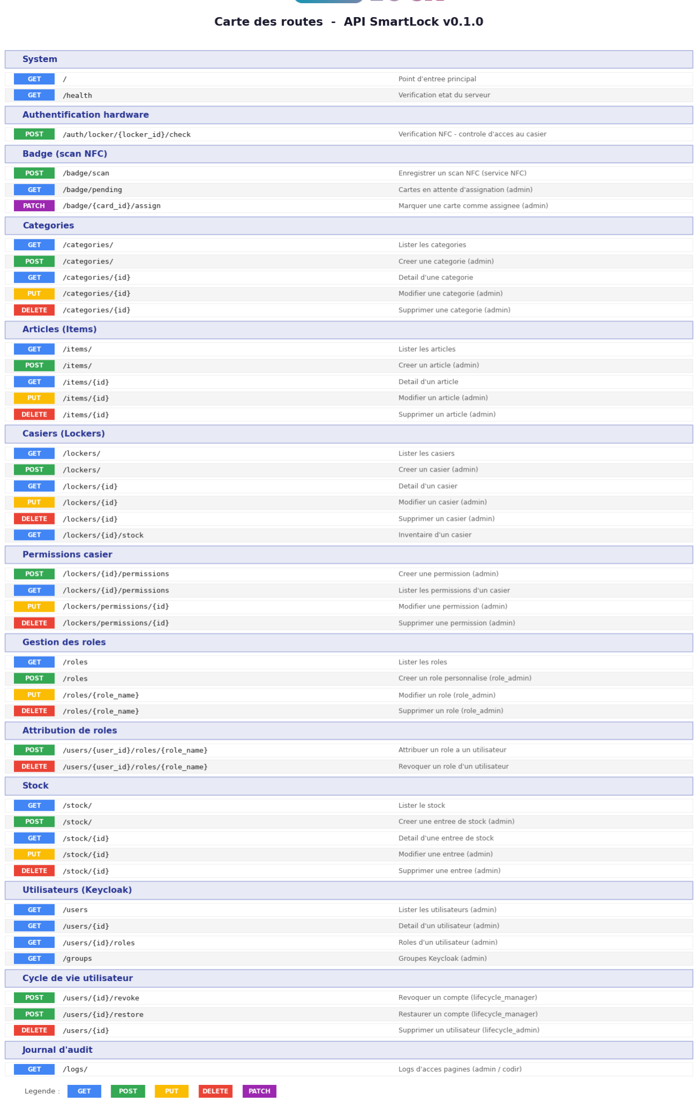
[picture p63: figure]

Figure

5 Listes des endpoints

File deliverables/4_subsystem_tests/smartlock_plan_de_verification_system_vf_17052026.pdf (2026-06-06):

# SmartLock


V2 - VF | Plan de vérification système | 17/05/2026
Rédacteur : Florian Cazac | Relecteurs : Augustin Winterbert, Alexandre Houdin, Guilhem Henoux , Lois H almaert, Yann Videmment | Jalon revue des tests

Validateurs : Florian Cazac

Présentation du projet :

- Le projet SmartLock modernise la gestion du matériel du DeVinci Fablab en remplaçant les serrures traditionnelles par un système d'accès sécurisé et connecté via badge NFC.
- Cette solution couple la sécurisation physique des armoires à une gestion centralisée des stocks pour garantir une traçabilité complète des emprunts en temps réel.
- A terme, la solution sera implémentée toutes les armoires du Fablab afin de sécuriser le matériel de l’espace.

## 1. Introduction

Ce document décrit le plan de vérification système du projet SmartLock. Il couvre la recette de chaque sous -système, la matrice de tests système, les scénarios d'intégration
bout-en-bout et les procédures de test pas | -à-pas à suivre pour valider le
1.1. Périmètre

Le plan couvre les 6 sous -systèmes suivants et leur intégration complète :

1.2. Légende des statuts
Symbole | Signification
Validé | Test exécuté avec succès, critères de recette atteints
En cours | Test en cours d'exécution ou sous -système partiellement validé
Bloqué | Test impossible en l'état - prérequis non satisfaits
Non commencé | Test planifié mais pas encore exécuté

2. Critères de recette par sous | -système
2.1. PCB custom | - Assemblage et soudure

Responsable : Guilhem Henoux

Statut : Validé

contacts, pas de ponts)

Aucun court - circuit entre les pistes (contrôle au multimètre)
Continuité vérifiée sur toutes les pistes critiques (alimentation, signaux I²C, GPIO) Composants CMS 0402/0603/0805 correctement soudés (pas de faux

Câble correctif optocoupler (broche 12V → broche 4 U5) en place et fonctionnel Inspection visuelle : aucun composant mal orienté ou manquant

2.2. Régulateurs DC -DC (MC34063ADR)

Responsable : Guilhem Henoux

Statut : En cours - bloqué par les résistances R_SC (commande Mouser/LCSC en

Tension de sortie U1 (12V → 5V) : >= 4.9V sans charge, >= 4.8V sous charge Raspberry Pi
Tension de sortie U2 (11.1V → 5V) : >= 4.9V sans charge, >= 4.8V sous charge écran 7"
Tension de sortie U3 (11.1V → 12V) : >= 11.8V pour alimentation solénoïde Tension de sortie U4 (12V → 12.6V) : charge batterie à <= 250mA sans surtension
Démarrage complet du Raspberry Pi Zero 2W sans redémarrage intempestif Démarrage de l'écran 7" HDMI sans coupure d'alimentation
2.3. BMS 3S et pack batteries Li -Ion

Responsable : Guilhem Henoux

Statut : En cours - intégration PCB en attente de la correction des régulateurs

Tension de chaque cellule < 4.2V après charge complète (protection surcharge active)
Protection sous -tension active (coupure si cellule < 2.5V)
Protection court - circuit active (coupure instantanée)
Charge correcte via régulateur U4 : courant de charge ~ 250mA, tension finale ~ 12.6V
Basculement automatique sur batterie lors d'une coupure secteur (sans interruption système)
Autonomie mesurée >= 30 min sous charge nominale (Raspberry Pi + écran)

2.4. Intégration mécanique

Responsable : Alexandre Houdin

Statut : En cours - modèle CAO en cours d'ajustement

Tous les composants (PCB, écran, RPi, PN532, solénoïde, capteur Hall) positionnés dans le boîtier
Câblage sans contrainte mécanique sur les connecteurs
Boîtier fermable sans forcer (aucun conflit géométrique)
Solénoïde correctement aligné avec le mécanisme de verrouillage du casier Capteur à effet Hall positionné pour détecter l'état ouvert/fermé du casier Accès lecteur NFC PN532 visible et accessible depuis l'extérieur du boîtier
2.5. Interface Homme -Machine (IHM)

Responsable : Loïs Halmaert

Statut : Validé

Démarrage automatique de l'IHM au boot du Raspberry Pi (sans intervention manuelle)
Lecture NFC détectée en < 2 secondes après présentation de la carte
Toutes les vues accessibles et fonctionnelles (home, navigation, sélection, panier, validation, accès, clôture)
Timer d'inactivité actif : 30s sur home -> fermeture, 90s sur autres vues -> retour home
Timer d'alerte : 10 min de casier ouvert -> alerte Discord envoyée
Mode SIMULATION_MODE bascule sans erreur entre mode réel et simulé Connexion à l'API confirmée (authentification Keycloak client_credentials réussie)
2.6. API d'authentification et d'autorisation

Responsable : Florian Cazac

Statut : Validé

nominales; fonctionnels

87/87 tests automatisés (pytest) passants sans échec
Endpoint POST /auth/locker/{id}/check répond en < 500ms en conditions

Authentification Keycloak opérationnelle (JWT valide, JWKS accessible)
Service accounts Raspberry Pi (smartlock -lockers) et NFC scanner (nfc -scanner)

Journal d'audit enregistre chaque tentative d'accès (accordée et refusée)

Base de données PostgreSQL accessible et migrations appliquées (alembic

API déployée via Docker Compose et accessible sur le réseau interne

## 3. Matrice de tests système

Le tableau ci -dessous liste l'ensemble des tests à réaliser au niveau système. Chaque
test est identifié par un code SYS | -XX, associé à un ou plusieurs sous | -systèmes, à un
ID | Test | Sous -système( s) | Responsabl e | Prérequis | Statut | Observations
SYS -01 | Démarrage complet sous alimentation secteur (RPi + écran) | PCB, DC -DC | Guilhem | R_SC remplacée s | Bloqué | En attente composants
SYS -02 | Démarrage complet sur batterie de secours | PCB, BMS, DC -DC | Guilhem | SYS -01 | Bloqué | En attente SYS -01
SYS -03 | Affichage IHM sur écran 7" Waveshare | DC -DC, RPi, IHM | Guilhem, Loïs | SYS -01 | Bloqué | En attente SYS -01
SYS -04 | Lecture NFC et identification utilisateur via API | IHM, RPi, API | Loïs, Florian | SYS -03 | Validé | Testé en SIMULATION_MOD E
SYS -05 | Ouverture casier sur badgeage autorisé (solénoïde) | IHM, API, PCB | Florian, Loïs , Guilhem | SYS -04 | Validé
SYS -06 | Refus d'accès -carte NFC inconnue | IHM, API | Florian | SYS -04 | Validé
SYS -07 | Refus d'accès -compte utilisateur révoqué | IHM, API | Florian | SYS -04 | Validé
SYS -08 | Refus d'accès -absence de permission sur le casier | IHM, API | Florian | SYS -04 | Validé
SYS -09 | Refus d'accès -permission expirée (valid_until dépassé) | IHM, API | Florian | SYS -04 | Validé
SYS -10 | Détection fermeture casier (capteur à effet Hall) | PCB, RPi, IHM | Guilhem, Loïs | SYS -05 | Non commencé

SYS -11 | Journal d'audit enregistré après chaque accès | API | Florian | SYS -05 | Validé | Vérifié via GET /logs
SYS -12 | Comportement dégradé lors d'une coupure API | IHM, RPi | Loïs | SYS -03 | Non commencé | Attendre timeout, afficher message erreur
SYS -13 | Alerte Discord après 10 min de casier ouvert | IHM | Loïs | SYS -05 | Validé | Timer_manager vérifié
SYS -14 | Basculement automatique sur batterie (coupure secteur simulée) | PCB, BMS | Guilhem | SYS -02 | Bloqué | En attente intégration BMS

## 4. Procédures de test pas - à- pas

4.1. Prerequisites techniques

Variables a definir avant de commencer (adapter selon votre .env) :

API_URL="https://api.smartlock.devinci-fablab.fr"KC_URL="https://auth.smartlock.devinci-fablab.fr"
REALM="smartlock" | # valeur KEYCLOAK_REALM dans .env
LOCKER_ID=1 | # ID du casier cible
CARD_UID="04:AB:CD:EF:12:34" | # UID brut de la carte NFC (lu par le PN532)
Obtenir le token RPi (client smartlock | -lockers, grant client_credentials) :

RPi_TOKEN=$(curl -s -X POST \ "$KC_URL/realms/$REALM/protocol/openid-connect/token" \
-d "grant_type=client_credentials" \
-d "client_id=smartlock-lockers" \
-d "client_secret=$LOCKER_CLIENT_SECRET" \
| jq -r '.access_token')
Obtenir un token admin (grant password) :

ADMIN_TOKEN=$(curl -s -X POST \ "$KC_URL/realms/$REALM/protocol/openid-connect/token" \ -d "grant_type=password" \
-d "client_id=smartlock-api" \
-d "username=$ADMIN_USER" \
-d "password=$ADMIN_PASSWORD" \
| jq -r '.access_token')
Outils requis : curl, jq (Windows : winget install jqlang.jq)
4.2. Prerequisites techniques

Variables a definir avant de commencer (adapter selon votre .env) :

API_URL="https://api.smartlock.devinci-fablab.fr"KC_URL="https://auth.smartlock.devinci-fablab.fr"
REALM="smartlock" | # valeur KEYCLOAK_REALM dans .env
LOCKER_ID=1 | # ID du casier cible
CARD_UID="04:AB:CD:EF:12:34" | # UID brut de la carte NFC (lu par le PN532)
Obtenir le token RPi (client smartlock | -lockers, grant client_credentials) :

RPi_TOKEN=$(curl -s -X POST \ "$KC_URL/realms/$REALM/protocol/openid-connect/token" \
-d "grant_type=client_credentials" \
-d "client_id=smartlock-lockers" \
-d "client_secret=$LOCKER_CLIENT_SECRET" \
| jq -r '.access_token')
Obtenir un token admin (grant password) :

ADMIN_TOKEN=$(curl -s -X POST \ "$KC_URL/realms/$REALM/protocol/openid-connect/token" \ -d "grant_type=password" \
-d "client_id=smartlock-api" \
-d "username=$ADMIN_USER" \
-d "password=$ADMIN_PASSWORD" \
| jq -r '.access_token')
Outils requis : curl, jq (Windows : winget install jqlang.jq)

4.3. Procédure A : Test d'accès complet - scénario nominal

Matériel nécessaire : alimentation secteur 220V, carte NFC enregistrée, multimètre, PC

Étape 1 - Mise sous tension :

Connecter l'alimentation secteur 220V au connecteur J8 du PCB
Vérifier la LED verte d'alimentation sur le PCB (confirme la tension 5V disponible) Mesurer la tension au multimètre sur le connecteur Raspberry Pi : doit être entre

Étape 2 - Démarrage système :

Attendre le démarrage complet du Raspberry Pi Zero 2W (environ 45 secondes) L'écran 7" Waveshare doit afficher l'IHM SmartLock dans les 60 secondes
Si l'écran reste noir après 90s, vérifier la tension U2 (problème régulateur)

Étape 3 - Vérification réseau et API :

Vérifier que le Raspberry Pi est connecté au réseau (LED réseau active ou ping

Tester l'accessibilité de l'API : GET https://api.smartlock.devinci -fablab.fr/health

Étape 4 - Test NFC et accès casier :

Prendre une carte NFC enregistrée (utilisateur avec permission can_open sur le

Présenter la carte devant le lecteur PN532 à moins de 5 cm

# Simulation depuis un terminal (sans le lecteur physique) curl -s -X POST "$API_URL/auth/locker/$LOCKER_ID/check" \

-H "Authorization: Bearer $RPi_TOKEN" \
-H "Content-Type: application/json" \
-d "{\"card_id\": \"$CARD_UID\"}"
# Reponse attendue :

# {"allowed": true, "display_name": "Prenom Nom", "permissions": {"permission_level": "can_open"}}

# Simulation depuis un terminal (sans le lecteur physique)

curl -s -X POST "$API_URL/auth/locker/$LOCKER_ID/check" \
-H "Authorization: Bearer $RPi_TOKEN" \
-H "Content-Type: application/json" \
-d "{\"card_id\": \"$CARD_UID\"}"
# Reponse attendue :

# {"allowed": true, "display_name": "Prenom Nom", "permissions": {"permission_level": "can_open"}}

Observer l'IHM : écran de bienvenue avec nom de l'utilisateur dans les 2

Observer le déclenchement du relais GPIO (clic audible ou LED indicatrice) Vérifier l'ouverture mécanique du casier

Étape 5 - Vérification du journal d'audit :

Depuis un PC, appeler GET /logs (avec token admin)

curl -s -H "Authorization: Bearer $ADMIN_TOKEN" \
"$API_URL/logs/?locker_id=$LOCKER_ID" | jq '.[0]'
# Reponse attendue :

# { "result": "allowed", "can_open": true, "user_id": "...", "username": "..." } curl -s -H "Authorization: Bearer $ADMIN_TOKEN" \

"$API_URL/logs/?locker_id=$LOCKER_ID" | jq '.[0]'
# Reponse attendue :

# { "result": "allowed", "can_open": true, "user_id": "...", "username": "..." }

Vérifier la présence d'une entrée : allowed=true, user_id correct, timestamp

Étape 6 - Fermeture et retour à l'accueil :

Vérifier que le capteur Hall détecte la fermeture (LED ou log) L'IHM doit revenir à l'écran d'accueil automatiquement

Critères de succès : | Toutes les étapes ci -dessus réussies sans erreur.
4.4. Procédure B : Tests de refus d'accès (INT | -2 à INT - 5)

Utiliser le meme token RPi qu'en Procedure A. Changer uniquement CARD_UID pour

# INT-2 : carte inconnue

curl -s -X POST "$API_URL/auth/locker/$LOCKER_ID/check" \ -H "Authorization: Bearer $RPi_TOKEN" \
-H "Content-Type: application/json" \
-d '{"card_id": "00:00:00:00:00"}'
# Attendu : {"allowed": false, "reason": "card_not_registered"} # INT-3 : compte revoque

# 1. Revoquer le compte via API admin :

curl -s -X POST "$API_URL/users/$USER_ID/revoke" \
-H "Authorization: Bearer $ADMIN_TOKEN"
# 2. Scanner la meme carte qu'en INT-1

# Attendu : {"allowed": false, "reason": "account_revoked"}

# INT-4 : pas de permission sur ce casier

# Utiliser une carte d'un utilisateur sans entree dans locker_permission pour ce casier # Attendu : {"allowed": false, "reason": "no_permission"}

# INT-5 : permission expiree

# Utiliser une carte d'un utilisateur dont valid_until est dans le passe

# (modifier la permission via PUT /lockers/{id}/permissions/{perm_id} avec valid_until passe)

# Attendu : {"allowed": false, "reason": "no_permission"}

Utiliser le meme token RPi qu'en Procedure A. Changer uniquement CARD_UID pour

# INT-2 : carte inconnue

curl -s -X POST "$API_URL/auth/locker/$LOCKER_ID/check" \ -H "Authorization: Bearer $RPi_TOKEN" \
-H "Content-Type: application/json" \
-d '{"card_id": "00:00:00:00:00"}'
# Attendu : {"allowed": false, "reason": "card_not_registered"} # INT-3 : compte revoque

# 1. Revoquer le compte via API admin :

curl -s -X POST "$API_URL/users/$USER_ID/revoke" \
-H "Authorization: Bearer $ADMIN_TOKEN"
# 2. Scanner la meme carte qu'en INT-1

# Attendu : {"allowed": false, "reason": "account_revoked"}

# INT-4 : pas de permission sur ce casier

# Utiliser une carte d'un utilisateur sans entree dans locker_permission pour ce casier # Attendu : {"allowed": false, "reason": "no_permission"}

# INT-5 : permission expiree

# Utiliser une carte d'un utilisateur dont valid_until est dans le passe

# (modifier la permission via PUT /lockers/{id}/permissions/{perm_id} avec valid_until passe)

# Attendu : {"allowed": false, "reason": "no_permission"}

Exécuter les 4 scénarios de refus successivement. Chaque scénario doit produire un

B1 - Carte inconnue :

Utiliser une carte NFC vierge (non enregistrée dans Keycloak)
Présenter au lecteur PN532 - résultat attendu : refus, log card_not_registered

B2 - Compte révoqué :

Via l'API admin : POST /users/{id}/revoke pour désactiver un compte test
Présenter la carte de cet utilisateur | - résultat attendu : refus, log

Restaurer le compte après le test : POST /users/{id}/restore

B3 - Absence de permission :

Utiliser une carte d'un utilisateur actif sans permission sur le casier cible Présenter au lecteur - résultat attendu : refus, log no_permission

B4 - Permission expirée :

Configurer une permission avec valid_until = date dans le passé (ex. 2026 | -01-

Présenter la carte de cet utilisateur - résultat attendu : refus, log expired Supprimer la permission test après vérification

Vérification finale : Consulter GET /logs pour confirmer les 4 entrées denied avec les

4.5. Procédure C : Test de robustesse - 25 badgeages consécutifs

# Boucle 25 badgeages consecutifs (Linux/macOS/WSL)

for i in $(seq 1 25); do
RESULT=$(curl -s -X POST "$API_URL/auth/locker/$LOCKER_ID/check" \ -H "Authorization: Bearer $RPi_TOKEN" \
-H "Content-Type: application/json" \
-d "{\"card_id\": \"$CARD_UID\"")
echo "Scan $i : $(echo $RESULT | jq -r '.allowed')"
sleep 0.5
done

# Verifier que 25 logs ont ete crees :

curl -s -H "Authorization: Bearer $ADMIN_TOKEN" \
"$API_URL/logs/?locker_id=$LOCKER_ID" | jq 'length'
# Attendu : 25

# Boucle 100 badgeages consecutifs (Linux/macOS/WSL)

for i in $(seq 1 25); do
RESULT=$(curl -s -X POST "$API_URL/auth/locker/$LOCKER_ID/check" \ -H "Authorization: Bearer $RPi_TOKEN" \
-H "Content-Type: application/json" \
-d "{\"card_id\": \"$CARD_UID\"")
echo "Scan $i : $(echo $RESULT | jq -r '.allowed')"
sleep 0.5
done

# Verifier que 25 logs ont ete crees :

curl -s -H "Authorization: Bearer $ADMIN_TOKEN" \
"$API_URL/logs/?locker_id=$LOCKER_ID" | jq 'length'
# Attendu : 25

Ce test vérifie la stabilité du système sous sollicitation répétée. À réaliser une fois tous

Préparation :

Système complet sous tension depuis au moins 10 minutes (température

Un utilisateur avec permission active sur le casier, carte NFC prête
Script de monitoring actif (logs API en temps réel : docker compose logs -f api)

Exécution :

chaque; déconnexion)

Effectuer 25 badgeages consécutifs en respectant un délai de 10 secondes entre

Après chaque badgeage, fermer le casier avant le suivant
Noter tout comportement anormal (lenteur, erreur IHM, refus inattendu,

Vérification :

(pas de dérive)

Consulter GET /logs : 25 entrées allowed=true attendues
Aucune erreur dans les logs Docker (docker compose logs api | grep ERROR)
Température du PCB mesurée au multimètre infra -rouge : doit rester < 60°C Tension alimentation mesurée après test : doit être identique à la mesure initiale

Critères de succès : 25/25 badgeages réussis, aucune erreur, températures et tensions

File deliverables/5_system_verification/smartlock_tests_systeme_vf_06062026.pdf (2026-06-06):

# SmartLock


V1- VF | Test Systeme | 06/06/2026
Rédacteur : Florian Cazac | Relecteurs : Augustin Winterbert, Alexandre Houdin, Guilhem Henoux, Lois Halmaert, Yann Videmment | Jalon tests Systeme

Validateurs : Florian Cazac

Présentation du projet :

- Le projet SmartLock modernise la gestion du matériel du DeVinci Fablab en remplaçant les serrures traditionnelles par un système d'accès sécurisé et connecté via badge NFC.
- Cette solution couple la sécurisation physique des armoires à une gestion centralisée des stocks pour garantir une traçabilité complète des emprunts en temps réel.
- A terme, la solution sera implémentée toutes les armoires du Fablab afin de sécuriser le matériel de l’espace.

## 1. Introduction

Ce document présente les tests système du projet SmartLock et leurs résultats finaux. Le projet SmartLock modernise la gestion du matériel du DeVinci FabLab en remplaçant les serrures traditionnelles par un système d'accès sécurisé par badge NFC, couplé à une gestion
centralisée des stocks et à un tableau de bord d'administration.

Le plan couvre les sous -systèmes suivants et leur intégration :

Zero 2W

- Interface Homme -Machine (IHM) : application Python/CustomTkinter sur Raspberry Pi
- API d'authentification et d'autorisation : FastAPI + Keycloak + PostgreSQL
- Dashboard d'administration : SvelteKit / Node.js
- Matériel : lecteur NFC PN532, solénoïde 12V, relais GPIO, écran tactile 7" 1024×600
- | Alimentation : 12V 3A secteur + convertisseur buck DC | -DC

### 1.2. Légende des statuts

Statut | Signification
Validé | Test exécuté avec succès, critères de recette atteints
En cours | Test en cours ou sous -système partiellement validé
Bloqué | Test impossible - prérequis non satisfaits
Non commencé | Test planifié mais pas encore exécuté
Non implémenté | Fonctionnalité hors périmètre de la version livrée

## 2. Architecture système testée

Couche; Technologie; Hébergement

Physique | RPi Zero 2W + NFC PN532 + Relais GPIO26 + Solénoïde 12V + Écran 7" | Armoire FabLab
IHM | Python 3.13 / CustomTkinter | Raspberry Pi Zero 2W
API | FastAPI (Python) + Keycloak (OIDC) + PostgreSQL | Serveur DeVinci (Docker)
Dashboard | SvelteKit / Node.js | Serveur DeVinci (Docker)

### 2.1. Composants matériels

Composant | Spécification | Rôle
Raspberry Pi Zero 2W | ARM Cortex -A53, 512 MB RAM, WiFi | Exécute l'IHM, contrôle GPIO
Solénoïde 12V | 12V DC, relais sur GPIO 26 (BCM) | Mécanisme de verrouillage
Alimentation | 12V 3A secteur | Source principale du système
Écran tactile 7" | Waveshare HDMI 1024×600, capacitif | Interface kiosque utilisateur
Convertisseur buck | 12V → 5V DC -DC | Alimentation RPi et écran
Lecteur NFC PN532 | I²C adresse 0x24, 13.56 MHz | Lecture des badges utilisateurs

## 3. 3. Critères de recette par sous -système

- Démarrage automatique de l'IHM au boot (sans intervention manuelle)
- Lecture NFC détectée en < 2 secondes après présentation de la carte
- Toutes les vues fonctionnelles : home, navigation, sélection, panier, validation, accès, clôture
- Timer d'inactivité actif : 2 min sur home → fermeture, 90s sur autres vues → retour home
- Mode SIMULATION_MODE bascule sans erreur entre mode réel et simulé
- Connexion API confirmée (Keycloak client_credentials réussi)

### 3.2. API d'authentification et d'autorisation

- 87/87 tests automatisés (pytest) passants sans échec
- Endpoint POST /auth/locker/{id}/check répond en < 500 ms en conditions nominales
- Authentification Keycloak opérationnelle (JWT valide, JWKS accessible)
- Service accounts smartlock -lockers et nfc -scanner fonctionnels
- Journal d'audit enregistre chaque tentative d'accès (accordée et refusée)
- Base PostgreSQL accessible, migrations appliquées (alembic upgrade head)
- API déployée via Docker Compose, accessible sur le réseau interne

3.3. Dashboard d'administration; Responsable : Yann Vidamment; Statut : Validé

- Authentification SSO Keycloak fonctionnelle (Authorization Code + PKCE)
- OTP requis pour les rôles T2+ (Bureau, Responsables)
- Gestion utilisateurs : liste, rôles, activation/révocation
- Gestion armoires : CRUD, matrice de permissions (rôle × armoire)
- Gestion stocks : vue globale, alertes stock bas, export CSV
- Journal d'audit consultable avec filtres, export CSV
- Application déployée via Docker, accessible sur le réseau interne (port 3000)

3.4. Lecteur NFC PN532; Responsable : Loïs Halmaert; Statut : Validé

- | Détecté sur le bus I²C à l'adresse 0x24 (vérifié via i2cdetect | -y 1)
- Badge détecté en moins de 2 secondes après présentation
- UID de carte transmis correctement à l'API

Responsable : Loïs Halmaert / Guilhem Henoux

- Relais GPIO 26 (BCM) activé depuis Python (RPi.GPIO)
- Activation pendant 5 secondes puis désactivation automatique
- Clic audible et tension 12V mesurée sur le solénoïde lors de l'activation
- Composants R_SC en attente de livraison (Mouser/LCSC)
- PCB prévu - emplacements disponibles, intégration non réalisée
- Basculement automatique sur batterie : NON TESTÉ
- Autonomie >= 30 min sous charge nominale : NON TESTÉ

Responsable : Guilhem Henoux / Loïs Halmaert

- | GPIO 27 réservé dans le code | - capteur non câblé physiquement
- La détection de fermeture utilise un timer de 5 secondes en remplacement

## 3.8. SKSM

Responsable : —
Statut : Non implémenté
- Non inclus dans le périmètre de la version livrée
- À définir et implémenter dans une version future
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

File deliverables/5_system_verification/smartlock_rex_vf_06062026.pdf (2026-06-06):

# SmartLock


V1- VF | Retour d’experience | 06/06/2026
Rédacteur : Equipe | Relecteurs : Augustin Winterbert, Alexandre Houdin, Guilhem Henoux, Lois Halmaert, Yann Videmment | Jalon tests Systeme

Validateurs : Florian Cazac

Présentation du projet :

- Le projet SmartLock modernise la gestion du matériel du DeVinci Fablab en remplaçant les serrures traditionnelles par un système d'accès sécurisé et connecté via badge NFC.
- Cette solution couple la sécurisation physique des armoires à une gestion centralisée des stocks pour garantir une traçabilité complète des emprunts en temps réel.
- A terme, la solution sera implémentée toutes les armoires du Fablab afin de sécuriser le matériel de l’espace.

## 1. Table des matières

## 2. Alexandre Houdin
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
